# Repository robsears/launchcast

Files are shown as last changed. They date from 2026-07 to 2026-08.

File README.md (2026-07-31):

# LaunchCast

**Live telemetry from launchpad to landing.**

A LoRa telemetry payload for model rockets, with a handheld ground station. Built around the Adafruit Feather RP2040 RFM95.

## Hardware

### Rocket payload (~44 g)

| Role | Part | Price (USD) |
|---|---|---|
| Flight computer + LoRa | [Feather RP2040 RFM95](https://www.adafruit.com/product/5714) |  $29.95 |
| GPS | [Mini GPS PA1010D](https://www.adafruit.com/product/4415) | $29.95 |
| 9-DoF IMU | [LSM6DSOX + LIS3MDL](https://www.adafruit.com/product/4517) | $19.95 |
| Barometer | [BMP580](https://www.adafruit.com/product/6411) | $7.95 |
| Power | [3.7v 500 mAh LiPo](https://www.adafruit.com/product/1578) | $7.95 |
| Recovery aid | [PS1240 piezo](https://www.adafruit.com/product/160) | $1.50 |
| Antenna | [915 MHz spring](https://www.adafruit.com/product/4269) | $0.95 |
| Total | - | **$97.75** |

### Handheld ground station

| Role | Part | Price (USD) |
|---|---|---|
| Display | [Sharp Memory 2.7" 400×240](https://www.adafruit.com/product/4694) | $44.95 |
| Flight computer + LoRa | [Feather RP2040 RFM95](https://www.adafruit.com/product/5714) |  $29.95 |
| GPS | [Mini GPS PA1010D](https://www.adafruit.com/product/4415) | $29.95 |
| Power | [3.7v 2500 mAh LiPo](https://www.adafruit.com/product/5714) | $14.95 |
| Tactile Inputs | [Universal Proto-board PCBs 2cm x 8cm - 3 Pack](https://www.adafruit.com/product/4783)<br />[Colorful Round Tactile Button Switch Assortment - 15 pack](https://www.adafruit.com/product/1009) | $8.20|
| Antenna | [SMA to uFL/u.FL/IPX/IPEX RF Adapter Cable](https://www.adafruit.com/product/851)<br />[Mini GSM/Cellular Quad-Band Antenna - 2dBi SMA Plug](https://www.adafruit.com/product/1859) | $9.90 |
| Total | - | **$137.90** |

All sensors chain on a single I²C bus via STEMMA QT. Only the Feathers require soldering.

---

## Software

I run on NixOS and make heavy use of Nix flakes. This, plus direnv, ensures that any Nix user who clones this repo will have an identical workspace with all necessary tools. This is especially nice because you won't need to deal with Python or Conda, or polluting other environments. Everything you need is symlinked in .

Go set up Nix, and then you can get a local dev environment by running:

```
nix develop
```

Nix is also great because we can run tests and `make` scripts through it as well, ensuring the build environment also has everything it needs to do the work:

```
nix run .#test  
python -m pytest tests/ -q
....................................................................................................                                                                                                                                                                    [100%]
100 passed in 0.05s
```

Check out the `apps` section of `nix flake show` to see other `nix run .#` actions:

```
├───apps
│   ├───aarch64-darwin omitted (use '--all-systems' to show)
│   ├───aarch64-linux omitted (use '--all-systems' to show)
│   └───x86_64-linux
│       ├───check: app
│       ├───default: app
│       ├───deploy-ground: app
│       ├───deploy-rocket: app
│       ├───doctor: app
│       ├───libs-ground: app
│       ├───libs-rocket: app
│       ├───lint: app
│       ├───monitor: app
│       ├───pull-log: app
│       ├───test: app
│       └───volumes: app
```

**Language:** CircuitPython.

## Repository layout

```
launchcast/
├── common/
│   └── packet.py       # wire format -- single source of truth
├── rocket/
│   ├── code.py         # flight firmware
│   └── boot.py         # filesystem remount + volume label
├── ground/
│   ├── code.py         # handheld firmware
│   └── boot.py         # volume label
├── tests/
│   ├── test_packet.py
│   └── test_flight_state.py
├── conftest.py         # CircuitPython hardware stubs
├── docs/wiring/        # Fritzing sketches
├── nix/                # devshell, apps, shared package set
└── Makefile            # test, lint, deploy, pull flight logs
```

`common/packet.py` is copied to both boards at deploy time rather than
imported as a package. CircuitPython has a flat filesystem — `code.py` and
`packet.py` sit side by side on the device — so the firmware does a bare
`import packet`. `conftest.py` puts `common/` on `sys.path` so the same
import resolves in CI. Change the format string once; both sides stay in
sync because there is only one file.

The two boards are identical hardware running different firmware. `boot.py`
labels each volume (`LC-ROCKET` / `LC-GROUND`) so `make deploy-rocket`
cannot target the handheld when both are plugged in.

---

## Tests

```
nix run .#test          # or: make test
nix run .#check         # test + lint
```

100 tests, ~0.15 s. Two files, testing very different things.

**`test_packet.py`** covers the wire format. Sizes are contractual — 40 bytes
downlink, 7 up — and a change that breaks a round trip breaks both boards
silently. It also checks the things that only matter when something has gone
wrong: frames from stuck-high or stuck-low lines, wrong packet types, values
that saturate rather than wrapping. A clipped accelerometer reading must not
change sign, because that would look like the rocket reversed direction.

**`test_flight_state.py`** covers the state machine, which is the logic that
runs exactly once per flight, irreversibly, a few hundred meters up. It
synthesizes a pressure and acceleration profile for a plausible D12-5 flight,
feeds it through `FlightState` at the real sample rate, and asserts both the
state sequence and the transition timings. Boost must fire shortly after
ignition but not before `BOOST_MIN_MS`; apogee must land near the true peak;
states must never regress.

The pair worth understanding is `test_a_brief_bump_does_not_trigger_boost`
and `test_a_sustained_bump_does_trigger_boost`. They bracket `BOOST_MIN_MS`
from both sides — too lax and handling the rocket on the pad starts the
flight, too aggressive and a real launch is missed.

The firmware imports `board`, `busio`, `digitalio` and friends at module
scope, none of which exist off-device. `conftest.py` stubs them. Nothing
there simulates hardware behavior — anything needing a real peripheral is a
bench test, not a CI test.

`d12_profile` is a shape, not a simulation: 1.6 s burn, ballistic coast,
5 m/s descent. It exists so the state machine sees realistic transitions.
After the first flight it should be replaced with real log data, at which
point these become regression tests against measured behavior.

## License

Apache License 2.0. See `LICENSE`.

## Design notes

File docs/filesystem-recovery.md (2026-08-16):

# Recovering a Corrupted Board Filesystem

What happened during a firmware update session on the rocket board, how we
diagnosed it, and the runbook for fixing it if it happens again (on either
board).

## What happened

While iterating on `rocket/boot.py`'s flight-mode/dev-mode logic, the rocket
board went through a lot of hard resets and power cycles in a short window --
BOOTSEL/RESET combos, unplug/replug to force a fresh `supervisor.runtime.
usb_connected` check, etc. At some point one of those resets landed mid-write,
and the board's internal FAT filesystem came out of it corrupted.

Symptom: the CIRCUITPY drive mounted with garbled, unreadable filenames (mojibake
instead of `code.py` / `packet.py`), and the volume showed up labeled as a raw
serial number (`C0E0-F50B`) instead of `LC-ROCKET`. That serial-number fallback
is the tell -- it's what a file manager shows when the volume label stored in
the filesystem's own root directory structure is unreadable. Practically, this
meant the board wasn't running any recognizable `code.py`, so it stopped
transmitting telemetry entirely (the ground station showed `NO TELEMETRY
rejects: 0` -- nothing arriving over the radio at all, as opposed to `rejects`
climbing, which would mean packets arriving but failing to decode).

## Why reflashing CircuitPython alone didn't fix it

The first fix attempt was to reflash CircuitPython from its `.uf2` (see
[Recovery runbook](#recovery-runbook) below). That did *not* fix it -- same
garbled files, same `C0E0-F50B`, right after the reflash.

Reason: flashing a CircuitPython `.uf2` replaces the interpreter/firmware only.
It does **not** reformat the internal filesystem partition unless CircuitPython
can't mount it at all. This board's corruption was bad enough to garble
filenames but not bad enough to make CircuitPython refuse to mount it, so the
same damaged filesystem just came right back after the reflash.

The actual fix has to be an explicit filesystem reformat, from the CircuitPython
REPL:

```python
import storage
storage.erase_filesystem()
```

This is CircuitPython's built-in "the filesystem is corrupt, rebuild it" tool.
It erases and reformats the internal flash filesystem and reboots.

## A red herring along the way: no `/dev/ttyACM*`

Partway through recovery, the serial port disappeared entirely (no
`/dev/ttyACM*` device at all). That's expected, not a new failure: the RP2040's
UF2 bootloader (`RPI-RP2`, seen in `lsusb` as `2e8a:0003 Raspberry Pi RP2
Boot`) is mass-storage-only and never presents a serial/CDC interface. If
you're mid-recovery and lose the serial port, check `lsusb` for that ID first
-- it just means the board is sitting in the bootloader waiting for a `.uf2`,
not that something new broke. A stale Nautilus/file-manager window can also
keep showing an old (corrupted) mount after the board has already re-entered
the bootloader -- don't trust a file manager's cached view here; re-check with
`lsusb` and `find /run/media/$USER -maxdepth 1`.

## Recovery runbook

1. **Note the CircuitPython version first**, if `boot_out.txt` is still
   readable (it survives corruption that garbles the other files, since it's
   regenerated fresh on every boot). It'll look like:
   ```
   Adafruit CircuitPython 10.2.1 on 2026-05-13; Adafruit Feather RP2040 RFM with rp2040
   Board ID:adafruit_feather_rp2040_rfm
   ```
   Matching the version avoids introducing a CircuitPython upgrade as an extra
   variable while you're debugging something else.

2. **Enter the UF2 bootloader**: hold **BOOT**, press and release **RESET**
   while still holding BOOT (or hold BOOT while plugging in USB). A drive
   named `RPI-RP2` should appear. Confirm with `lsusb` if unsure --
   `2e8a:0003 Raspberry Pi RP2 Boot` means you're in.

3. **Copy the matching `.uf2`** (this repo keeps a copy of the one used for
   both boards at
   `docs/downloads/adafruit-circuitpython-adafruit_feather_rp2040_rfm-en_US-10.2.1.uf2`)
   onto `RPI-RP2`, and force a `sync` before the board has a chance to reset
   itself mid-write:
   ```
   cp docs/downloads/adafruit-circuitpython-*.uf2 /run/media/$USER/RPI-RP2/ && sync
   ```
   The board reboots on its own once the copy is complete.

4. **Reformat the filesystem from the REPL** -- this is the step that
   actually fixes corruption, not step 3:
   ```
   make monitor          # or screen/minicom on /dev/ttyACM0
   ```
   At the `>>>` prompt (Ctrl-C first if something's running):
   ```python
   import storage
   storage.erase_filesystem()
   ```
   The board erases, reformats, and reboots automatically.

5. **Confirm it's clean**: `make volumes` should now show a plain `CIRCUITPY`
   volume (not yet relabeled).

6. **Re-provision from the repo**:
   ```
   make setup-rocket      # or setup-ground -- labels the volume, needs a reset after
   #  ... reset the board ...
   make volumes           # confirm it now shows LC-ROCKET / LC-GROUND
   make libs-rocket        # or libs-ground -- reinstalls CircuitPython libraries,
                            # wiped along with everything else by the reformat
   make deploy-rocket      # or deploy-ground
   ```

## Prevention

The root trigger was resetting/unplugging the board while a write could still
be in flight -- easy to do when iterating quickly on `boot.py` and wanting a
truly fresh boot each time. Where practical, let a write finish and the OS
finish flushing (`sync`, or just give the "copied" progress bar/notification a
moment to clear) before pulling power or hitting RESET, especially right after
`boot.py`'s own remount dance runs.

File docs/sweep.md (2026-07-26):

# Buzzer Frequency Sweep 

The payload Feather has a little piezo buzzer soldered across D5/D6, which it uses to "chirp". Piezoelectric buzzers like this use [piezoelectric materials](https://en.wikipedia.org/wiki/Piezoelectricity), which essentially convert electricity to sound. More specifically, they use electric _frequencies_; simply applying a voltage across the material doesn't cause it to make a sound. It's the oscillation that does it.

Because of this, piezoelectric buzzers have a couple of [resonance frequencies](https://en.wikipedia.org/wiki/Resonance), at which they produce higher auditory volumes. The piezo buzzer I am using is a [PS1240](https://www.adafruit.com/product/160) ([specs](PS1240-piezo.pdf)), which indicates that peak volumes with an input frequency around 4500 Hz. But that's just from a random sample, and also it's based on a 3V input.

The reason for putting the buzzer across D5/D6 is I can oscillate the voltage of the pins from -3.3 to +3.3, giving me an actual range of anbout 6.6V across the leads, and we have no data on how loud we can get the buzzer with a 6V square-wave voltage.

To ensure we get the loudest frequency, we'll perform a sweep test with a cell phone SPL meter app. We'll do some coarse measurements to get an idea where the peaks are, and then another pass to refine it.

This is the code:

```python
"""
Finds the loudest drive frequency for THIS specific PS1240 in its mounting.
Piezo resonance is sharp and part-specific; the datasheet nominal (4 kHz) is
a starting point, not the answer.

Wiring: buzzer across D5 and D6 (differential drive, ~6.6 Vp-p).

Method:
  1. Run this with an SPL meter app on your phone at a FIXED distance
     (10 cm to match the datasheet, or 30 cm for convenience -- just keep
     it constant).
  2. Quiet room. Note the dB reading for each frequency as it's announced
     on the serial console.
  3. Find the peak, then narrow with FINE_SWEEP around it.

Differential drive note: two PWM channels, same frequency. CircuitPython
does not guarantee they run 180 deg out of phase, so you may see less than
the theoretical +6 dB over single-ended. Still the right way to wire it.
"""

import time
import board
import pwmio

# --- sweep configuration -----------------------------------------------------

COARSE_START = 2000
COARSE_STOP = 10000
COARSE_STEP = 250

HOLD_S = 3.0     # time to hold each tone (read the meter during this)
GAP_S = 1.0      # silence between tones
DUTY = 32768     # 50% square

# After the coarse sweep finds a peak, set this and re-run to narrow.
FINE = False
FINE_CENTER = 4000
FINE_SPAN = 400
FINE_STEP = 25

# --- drive -------------------------------------------------------------------

hi = pwmio.PWMOut(board.D5, frequency=COARSE_START, duty_cycle=0,
                  variable_frequency=True)
lo = pwmio.PWMOut(board.D6, frequency=COARSE_START, duty_cycle=0,
                  variable_frequency=True)

def tone(freq):
    hi.frequency = freq
    lo.frequency = freq
    hi.duty_cycle = DUTY
    lo.duty_cycle = DUTY

def silence():
    hi.duty_cycle = 0
    lo.duty_cycle = 0

def sweep(start, stop, step):
    print("--- sweep {}-{} Hz, step {} ---".format(start, stop, step))
    print("hold each tone for {:.0f}s, note the dB reading".format(HOLD_S))
    print()
    for freq in range(start, stop + 1, step):
        print(">>> {} Hz".format(freq))
        tone(freq)
        time.sleep(HOLD_S)
        silence()
        time.sleep(GAP_S)
    print()
    print("--- sweep complete ---")

# --- run ---------------------------------------------------------------------

silence()
time.sleep(1.0)

if FINE:
    sweep(FINE_CENTER - FINE_SPAN, FINE_CENTER + FINE_SPAN, FINE_STEP)
else:
    sweep(COARSE_START, COARSE_STOP, COARSE_STEP)

silence()
print("done. Peak frequency goes in BUZZER_HZ.")

while True:
    time.sleep(1)
```

For me, this ended up being about 5250 Hz, which I measured to be around 103 dB a few inches away.

In terms of sound attenuation, the volume of the buzzer at increasing distance  would roughly be:

| Distance (ft) | Decibels | Sounds like |
|---|---|---|
| 0 | 103 | Motorcycle |
| 10 | 63 | Normal speech |
| 25 | 55 | Light traffic |
| 50 | 49 | Light traffic |
| 100 | 43 | Soft music |
| 250 | 35 | Whisper |

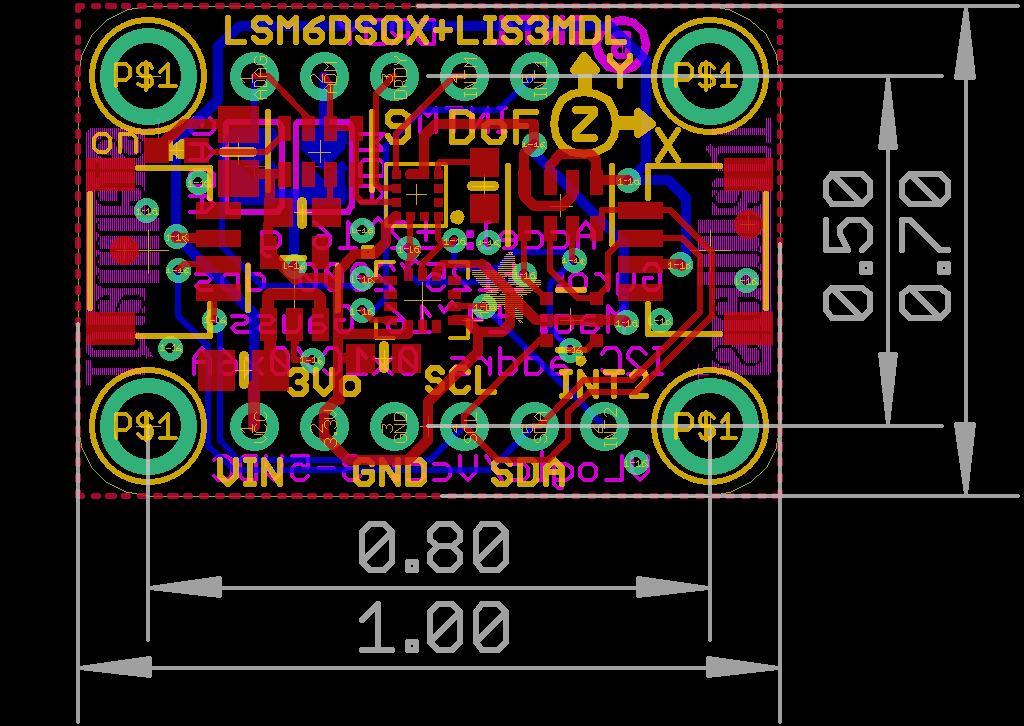
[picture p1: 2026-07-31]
docs/images/lsm6dsox-lis3mdl.png

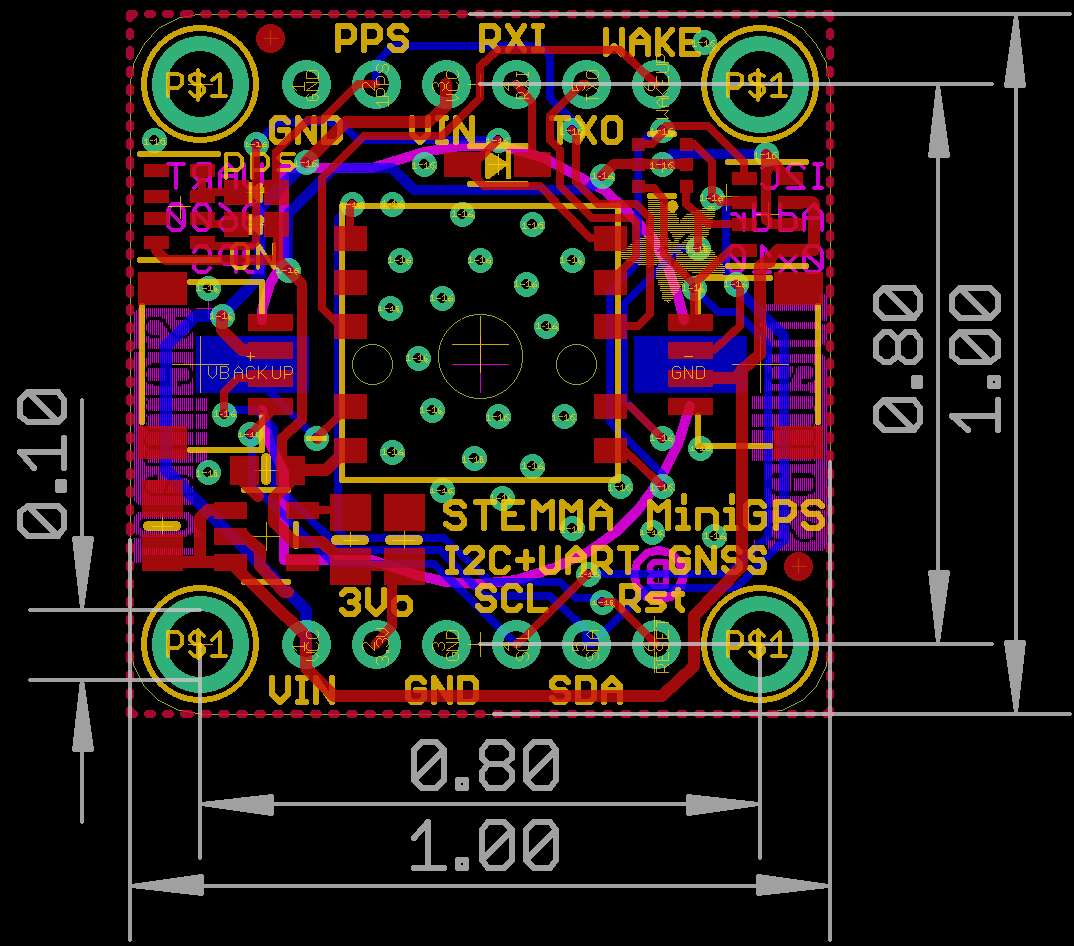
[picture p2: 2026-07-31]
docs/images/gps.png

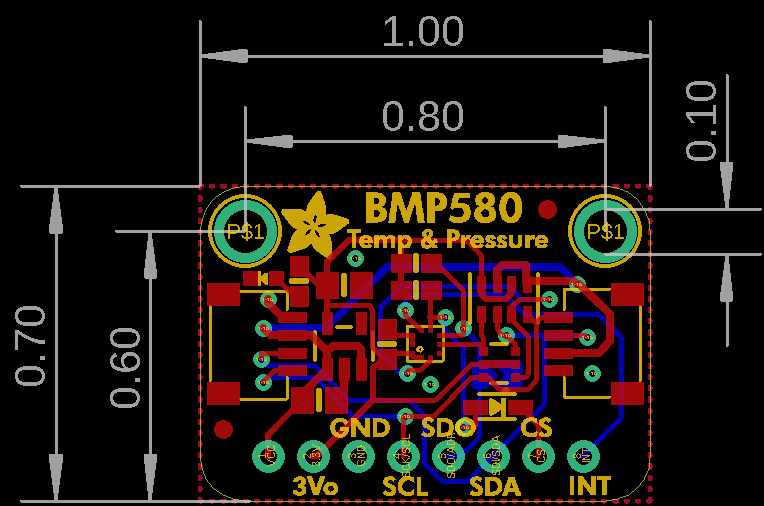
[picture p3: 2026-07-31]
docs/images/bmp580.png

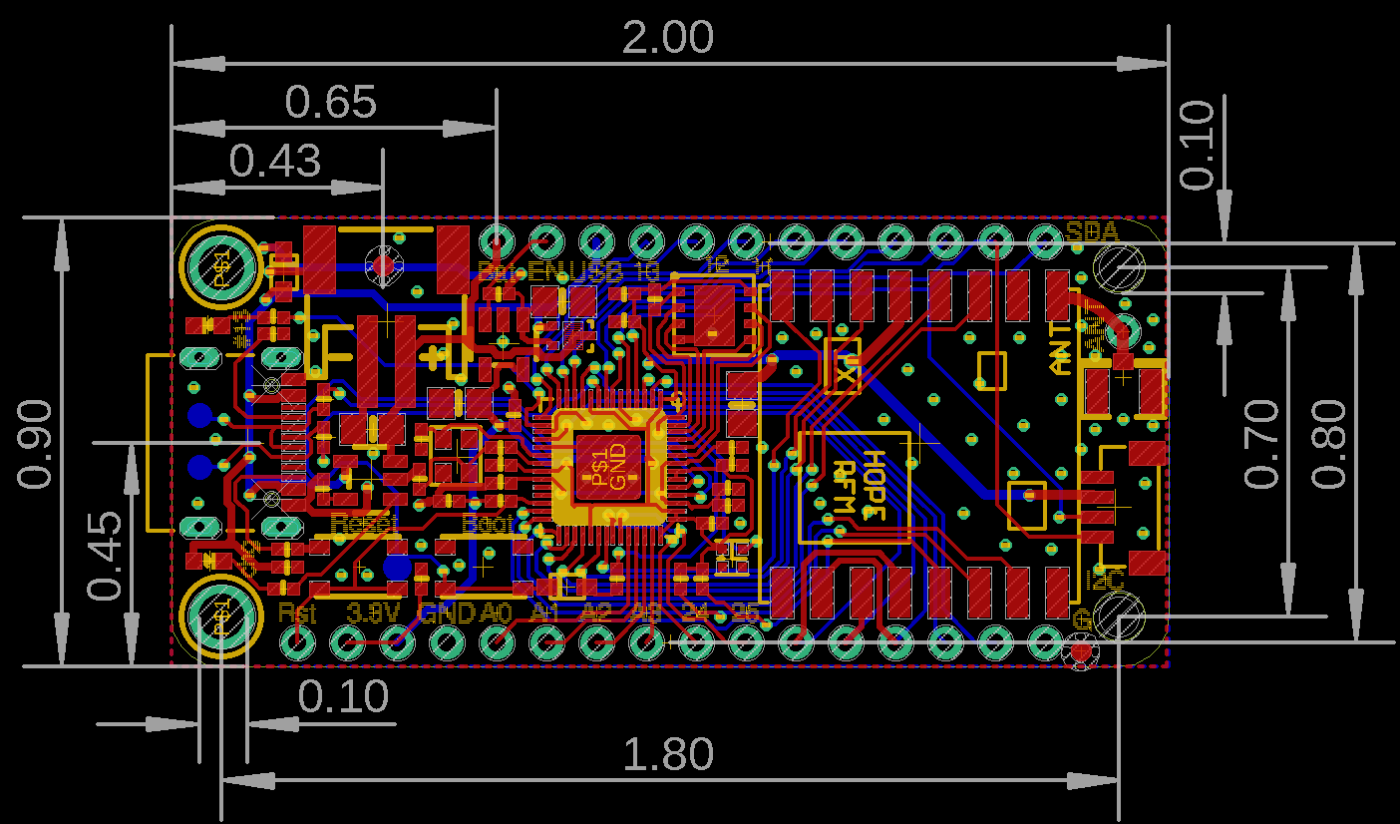
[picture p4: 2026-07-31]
docs/images/feather.png

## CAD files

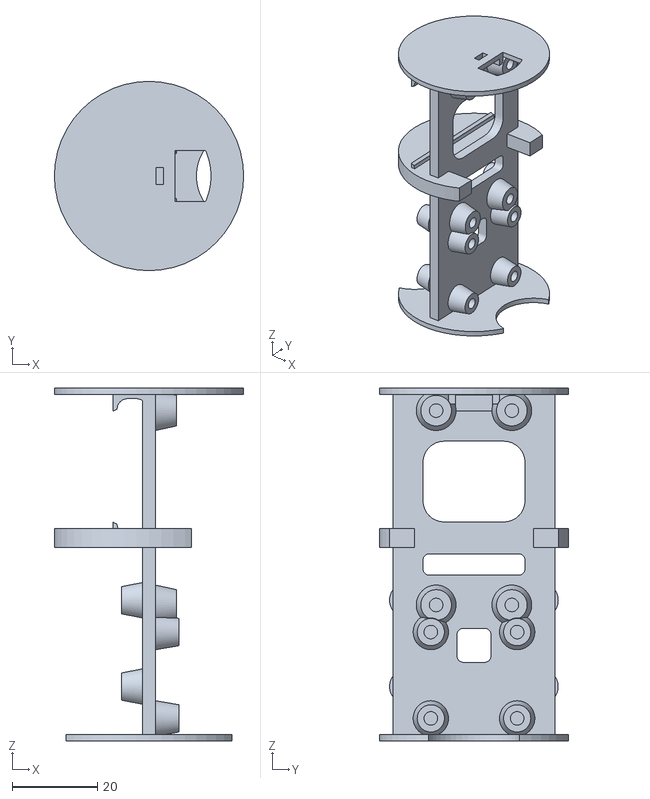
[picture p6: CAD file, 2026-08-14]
docs/cad/sled.stl
44.5 x 44.5 x 83.0

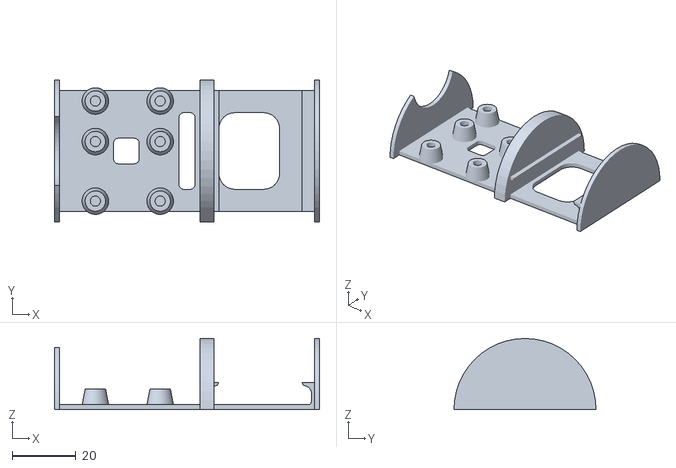
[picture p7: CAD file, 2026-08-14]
docs/cad/sled-side-b.stl
83.0 x 44.5 x 22.2

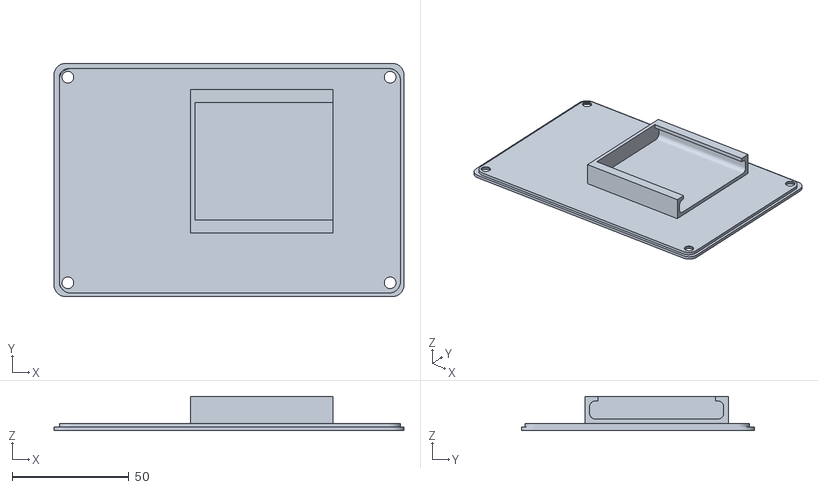
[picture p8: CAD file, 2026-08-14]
docs/cad/handheld - lid no txt.stl
150.0 x 100.0 x 14.8

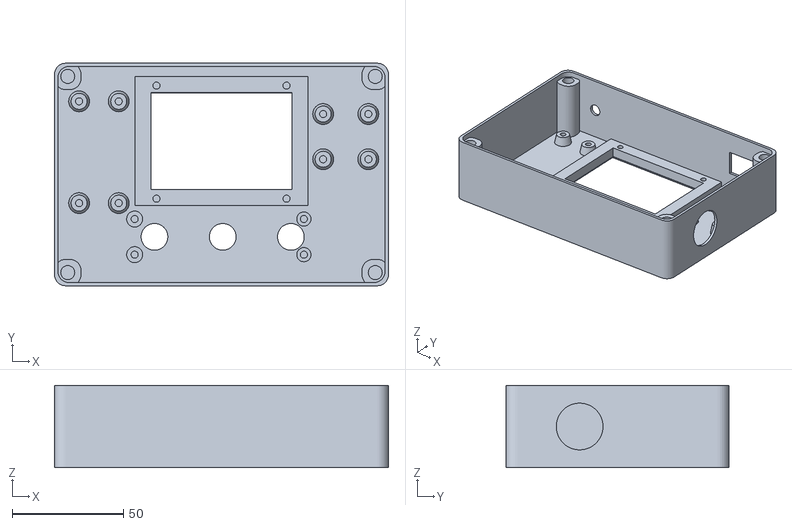
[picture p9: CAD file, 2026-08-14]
docs/cad/handheld - box.stl
150.0 x 100.0 x 37.0

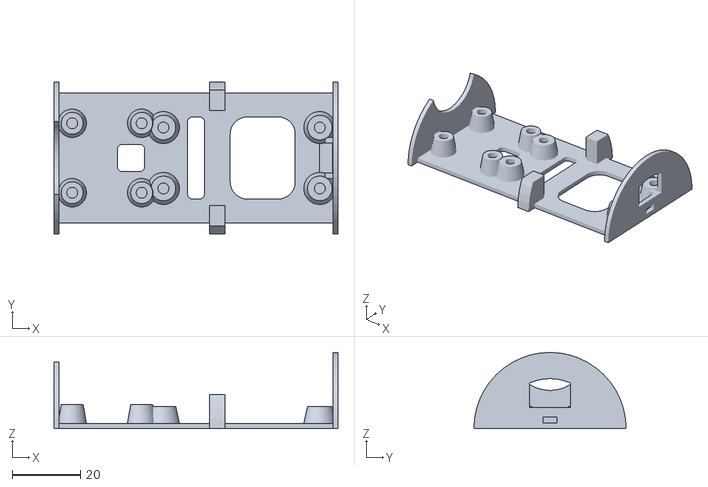
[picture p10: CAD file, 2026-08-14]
docs/cad/sled-side-a.stl
83.0 x 44.5 x 22.2

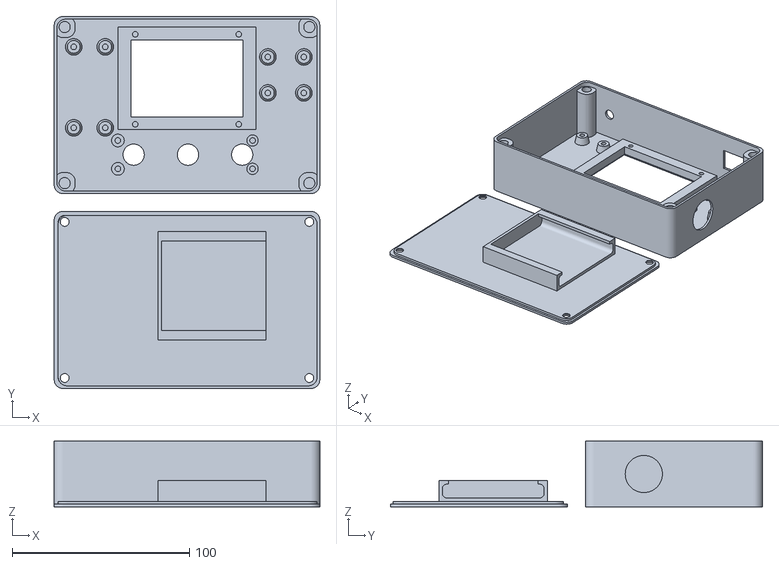
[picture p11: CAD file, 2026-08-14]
docs/cad/handheld.stl
150.0 x 210.0 x 37.0

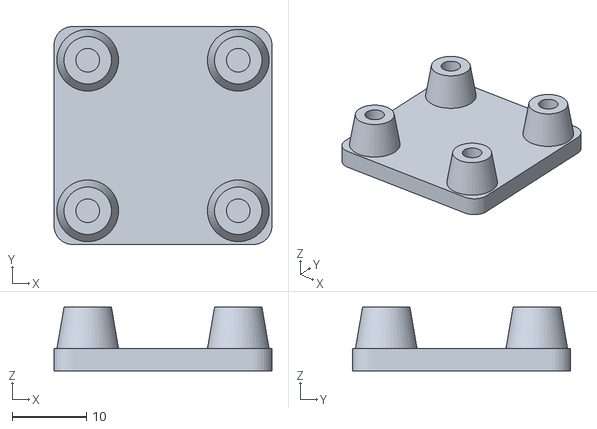
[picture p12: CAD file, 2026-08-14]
docs/cad/gps_coupon.stl
29.4 x 29.4 x 8.60

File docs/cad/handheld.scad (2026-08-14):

SHOW_GHOSTS = false;
SHOW_LID    = true;
SHOW_BOX    = false;
$fn = 48;

// ---- Footprints ----
PCB_RADIUS    = 2.5;    // Corner radius of the PCB
PCB_THICKNESS = 2.0;    // Thickness of PCB
PCB_HOLE_D    = 2.5;    // Diameter of pass-thru holes on PCB

// ---- Feather ----
FEATHER_Z      = 50.8;  // 2.00"
FEATHER_Y      = 22.9;  // 0.90"
FEATHER_HOLE_Z = 45.7;  // 1.80"
FEATHER_HOLE_Y = 17.8;  // 0.70"

// ---- GPS ----
GPS_Z      = 25.4;      // 1.00"
GPS_Y      = 25.4;      // 1.00"
GPS_HOLE_Z = 20.3;      // 0.80"
GPS_HOLE_Y = 20.3;      // 0.80"

// ---- Cutouts --
USB_CHARGER_D = 21.0;
ANTENNA_D     = 6.5;
ONOFF_X       = 19.5;
ONOFF_Z       = 13.5;

// ---- Battery ----
BATTERY_X = 61.0;
BATTERY_Y = 57.5;
BATTERY_Z = 7.75;
BATTERY_HOLDER_THICKNESS = 2.0;

// ---- Button Pad ----
BUTTON_PAD_X = 80.0;
BUTTON_PAD_Y = 20.0;
BUTTON_PAD_Z = PCB_THICKNESS;
BUTTON_PAD_POST_H = 18.1; //OAL of the button
BUTTON_PAD_HOLE_X = 76;
BUTTON_PAD_HOLE_Y = 16;
BUTTON_PAD_HOLE_D = 2.0;
BUTTON_BASE_X     = 12.0;
BUTTON_BASE_Y     = 12.0;
BUTTON_BASE_Z     = 6.4;
BUTTON_PLUNGER_X  = 3.8;
BUTTON_PLUNGER_Y  = 3.8;
BUTTON_PLUNGER_Z  = 3.9;
BUTTON_BUTTON_BASE_H = 1.4;
BUTTON_BUTTON_BASE_D = 12.8;
BUTTON_BUTTON_BODY_H = 4.4;
BUTTON_BUTTON_BODY_D = 12.0;

// ---- Inserts (M2.5 x D3.0 x L4.0) ----
INSERT_BORE_D          = 3.2; // DIA of pilot hole
INSERT_DEPTH           = 5.0;
INSERT_WALL_THICKNESS  = 2.0;
INSERT_WALL_THICKNESS_MIN = 1.6;
INSERT_FLOOR_THICKNESS = 1.0;

POST_OD_HEAVY = ((INSERT_BORE_D / 2) + INSERT_WALL_THICKNESS)*2;  // Feather, battery bar
POST_OD_LIGHT = ((INSERT_BORE_D / 2) + INSERT_WALL_THICKNESS)*2;  // GPS, IMU, BMP
POST_H_STD    = max(4.5, INSERT_DEPTH);
POST_H_GPS    = max(5.6, INSERT_DEPTH);;  // clears 4.12mm coin holder + 1.5mm

// -- Screen dimensions
SCREEN_PCB_X = 63.5;              // 2.50"
SCREEN_PCB_Y = 55.88;             // 2.20"
SCREEN_PCB_HOLES_X = 58.42;       // 2.30"
SCREEN_PCB_HOLES_Y = 50.8;        // 2.00"
SCREEN_PCB_HOLE_OFFSET = 2.54;     //
SCREEN_DISPLAY_X = SCREEN_PCB_X;  // TODO: measure?
SCREEN_DISPLAY_Y = 43.4;          // Caliper measurement
SCREEN_DISPLAY_Y_OFFSET = 6.75;   // Caliper measurement
SCREEN_DISPLAY_Z = PCB_THICKNESS; // TODO: measure? Does it matter?
SCREEN_DISPLAY_GRADE = 5;

// Unit dimensions
HANDHELD_THICKNESS = 1.5;
HANDHELD_TOP_X     = 150;
HANDHELD_TOP_Y     = 100;
HANDHELD_TOP_Z     = SCREEN_DISPLAY_Z;
HANDHELD_OVERALL_Z = 37;
HANDHELD_FILLET    = 5.0;
HANDHELD_INSERT_THICKNESS = INSERT_DEPTH + INSERT_FLOOR_THICKNESS;
HANDHELD_DISPLAY_BORDER = (INSERT_BORE_D + 2 * INSERT_WALL_THICKNESS) * 2;
HANDHELD_DISPLAY_X = (HANDHELD_TOP_X - SCREEN_DISPLAY_X)/2;
HANDHELD_DISPLAY_Y = (HANDHELD_TOP_Y - SCREEN_DISPLAY_Y - 20);

HEAT_SET_INSERT_D     = 6.3;
HEAT_SET_INSERT_WALL  = 2.8;
HEAT_SET_INSERT_DEPTH = 8.0;

echo(16.5 + BATTERY_Z + 2*BATTERY_HOLDER_THICKNESS + 2.5 * HANDHELD_THICKNESS);

module rounded_rect(x, y, z, r, $fn=32) {
  translate([x/2, y/2, 0]) {
    linear_extrude(height=z)
    minkowski() {
      square([x - 2*r, y - 2*r], center=true);
      circle(r=r);
    }    
  }
}

module ghost(y, z, col) {
  color(col,0.35)
    rounded_rect(y, z, PCB_THICKNESS, PCB_RADIUS);
}

module screen_ghost() {
  pcb_hole_x = (SCREEN_PCB_X - SCREEN_PCB_HOLES_X)/2;
  pcb_hole_y = (SCREEN_PCB_Y - SCREEN_PCB_HOLES_Y)/2;
  union() {
    difference() {
      color("YellowGreen",1) {
        cube([SCREEN_PCB_X, SCREEN_PCB_Y, PCB_THICKNESS]);
      }
      translate ([pcb_hole_x, pcb_hole_y, 0]) { cylinder(h = PCB_THICKNESS, r = PCB_HOLE_D/2); }
      translate ([pcb_hole_x + SCREEN_PCB_HOLES_X, pcb_hole_y, 0]) { cylinder(h = PCB_THICKNESS, r = PCB_HOLE_D/2); }
      translate ([pcb_hole_x, pcb_hole_y + SCREEN_PCB_HOLES_Y, 0]) { cylinder(h = PCB_THICKNESS, r = PCB_HOLE_D/2); }
      translate ([pcb_hole_x + SCREEN_PCB_HOLES_X, pcb_hole_y + SCREEN_PCB_HOLES_Y, 0]) { cylinder(h = PCB_THICKNESS, r = PCB_HOLE_D/2); }
    }
    color("Black",0.35)
      translate([0, SCREEN_DISPLAY_Y_OFFSET, PCB_THICKNESS]) {
        cube([SCREEN_DISPLAY_X, SCREEN_DISPLAY_Y, PCB_THICKNESS]);
      }
  }
}

// adapted from docs:
// https://en.wikibooks.org/wiki/OpenSCAD_User_Manual/Primitive_Solids#polyhedron
module screen_cutout() {
  CubePoints = [
    [  0,                                      0,                                        0 ],                          //0
    [ SCREEN_DISPLAY_X,                        0,                                        0 ],                          //1
    [ SCREEN_DISPLAY_X,                        SCREEN_DISPLAY_Y,                         0 ],                          //2
    [ 0,                                       SCREEN_DISPLAY_Y,                         0 ],                          //3
    [ -SCREEN_DISPLAY_GRADE,                   -SCREEN_DISPLAY_GRADE,                    HANDHELD_INSERT_THICKNESS ],  //4
    [ SCREEN_DISPLAY_X + SCREEN_DISPLAY_GRADE, -SCREEN_DISPLAY_GRADE,                    HANDHELD_INSERT_THICKNESS ],  //5
    [ SCREEN_DISPLAY_X + SCREEN_DISPLAY_GRADE, SCREEN_DISPLAY_Y + SCREEN_DISPLAY_GRADE,  HANDHELD_INSERT_THICKNESS ],  //6
    [ -SCREEN_DISPLAY_GRADE,                   SCREEN_DISPLAY_Y + SCREEN_DISPLAY_GRADE,  HANDHELD_INSERT_THICKNESS  ]  //7
  ];
    
  CubeFaces = [
    [0,1,2,3],  // bottom
    [4,5,1,0],  // front
    [7,6,5,4],  // top
    [5,6,2,1],  // right
    [6,7,3,2],  // back
    [7,4,0,3]]; // left
    
  polyhedron( CubePoints, CubeFaces );
}

module post(x, y, h, od) {
  rotate([0, -90, 0]) {
    translate([x, y, 0]) {
      difference() {
        cylinder(h = h, r1 = od/2, r2 = 1.3 * (od/2));
        translate([0, 0, INSERT_DEPTH-h]) {
          cylinder(h = INSERT_DEPTH, r = INSERT_BORE_D/2);
        }
      }
      if (SHOW_GHOSTS) {
        translate([0, 0, h - INSERT_DEPTH]) {
          color("Magenta",0.35)
            cylinder(h = INSERT_DEPTH, r = INSERT_BORE_D/2);
        }
      }
    }
  }
}

module post_feather(x, y) {
  post(x, y, POST_H_STD, POST_OD_HEAVY);
}

module post_gps(x, y) {
  post(x, y, POST_H_GPS, POST_OD_LIGHT);
}

// --- Feather Mounts + Ghost
// Posts flush with X=0, YZ at midpoint
module feather_posts() {
  rotate([90, -90, 0]) {
    translate([POST_H_STD, 0, 0]) {
      if (SHOW_GHOSTS) {
        translate([0, -FEATHER_Y/2, -FEATHER_Z/2]) {rotate([90, 0, 90]) {feather_ghost();}}
      }
      translate([0, -FEATHER_HOLE_Y/2, FEATHER_HOLE_Z/2]) {
        post_feather(0, 0);
        post_feather(0, FEATHER_HOLE_Y);
        post_feather(-FEATHER_HOLE_Z, 0);
        post_feather(-FEATHER_HOLE_Z, FEATHER_HOLE_Y);
      }
    }
  }
}

module feather_ghost() {
  difference() {
    ghost(FEATHER_Y, FEATHER_Z, "GreenYellow");
    translate([0, -FEATHER_HOLE_Y/2, -FEATHER_HOLE_Z/2]) {
      rotate([0, 90, 0]) {
        translate([0, 0, 0]) {cylinder(h = PCB_THICKNESS, r = PCB_HOLE_D/2);}
        translate([0, FEATHER_HOLE_Y, 0]) {cylinder(h = PCB_THICKNESS, r = PCB_HOLE_D/2);}
        translate([-FEATHER_HOLE_Z, 0, 0]) {cylinder(h = PCB_THICKNESS, r = PCB_HOLE_D/2);}
        translate([-FEATHER_HOLE_Z, FEATHER_HOLE_Y, 0]) {cylinder(h = PCB_THICKNESS, r = PCB_HOLE_D/2);}
      }
    }
  }
}

// --- GPS Mounts + Ghost
// Posts flush with X=0, YZ at midpoint
module gps_posts() {
  rotate([90, -90, 0]) {
    translate([POST_H_GPS, 0, 0]) {
      if (SHOW_GHOSTS) {
        translate([0, -GPS_Y/2, -GPS_Z/2]) {rotate([90, 0, 90]) {gps_ghost();}}
      }
      translate([0, -GPS_HOLE_Y/2, GPS_HOLE_Z/2]) {
        post_gps(0, 0);
        post_gps(0, GPS_HOLE_Y);
        post_gps(-GPS_HOLE_Z, 0);
        post_gps(-GPS_HOLE_Z, GPS_HOLE_Y);
      }
    }
  }
}

module gps_ghost() {
  difference() {
    ghost(GPS_Y, GPS_Z, "DeepSkyBlue");
    translate([0, -GPS_HOLE_Y/2, -GPS_HOLE_Z/2]) {
      rotate([0, 90, 0]) {
        translate([0, 0, 0]) {cylinder(h = PCB_THICKNESS, r = PCB_HOLE_D/2);}
        translate([0, GPS_HOLE_Y, 0]) {cylinder(h = PCB_THICKNESS, r = PCB_HOLE_D/2);}
        translate([-GPS_HOLE_Z, 0, 0]) {cylinder(h = PCB_THICKNESS, r = PCB_HOLE_D/2);}
        translate([-GPS_HOLE_Z, GPS_HOLE_Y, 0]) {cylinder(h = PCB_THICKNESS, r = PCB_HOLE_D/2);}
      }
    }
  }
}

module button() {
  union() {
    cube([BUTTON_BASE_X, BUTTON_BASE_Y, BUTTON_BASE_Z]);
    translate([(BUTTON_BASE_X - BUTTON_PLUNGER_X)/2, (BUTTON_BASE_Y - BUTTON_PLUNGER_Y)/2, BUTTON_BASE_Z]) {
      cube([BUTTON_PLUNGER_X, BUTTON_PLUNGER_Y, BUTTON_PLUNGER_Z]);
    }
    translate([
      BUTTON_BASE_X/2, BUTTON_BASE_Y/2, BUTTON_BASE_Z + BUTTON_PLUNGER_Z
    ]) { cylinder(h = BUTTON_BUTTON_BASE_H, r = BUTTON_BUTTON_BASE_D/2); }
    translate([
      BUTTON_BASE_X/2, BUTTON_BASE_Y/2, BUTTON_BASE_Z + BUTTON_PLUNGER_Z + BUTTON_BUTTON_BASE_H
    ]) { cylinder(h = BUTTON_BUTTON_BODY_H, r = BUTTON_BUTTON_BODY_D/2); }
  }
}
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

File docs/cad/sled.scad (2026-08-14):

SHOW_GHOSTS = false;
SHOW_COUPONS = false;
SHOW_SLED = true;
$fn = 48;

// ---- Spine ----
SPINE_Z       = 80.0;
SPINE_Y       = 38.0;   // set by battery pocket (30 + 2*4mm walls); bore limit
SPINE_THICK   = 3.0;

// ---- Inserts (M2.5 x D3.0 x L4.0) ----
INSERT_BORE_D = 3.2; // DIA of pilot hole
INSERT_DEPTH  = 5.0;
INSERT_WALL_MIN_THICKNESS = 1.6;
INSERT_WALL_MAX_THICKNESS = 2.0;
BOLT_HOLE_D = 3.2;      // clearance for M3 alignment bolts (or 2.6 for M2.5)

// ---- Posts (sized to load) ----
POST_OD_HEAVY = ((INSERT_BORE_D / 2) + INSERT_WALL_MAX_THICKNESS)*2;  // Feather, battery bar
POST_OD_LIGHT = ((INSERT_BORE_D / 2) + INSERT_WALL_MIN_THICKNESS)*2;  // GPS, IMU, BMP
POST_H_STD    = max(4.5, INSERT_DEPTH);
POST_H_GPS    = max(5.6, INSERT_DEPTH);;  // clears 4.12mm coin holder + 1.5mm

// ---- Footprints ----
PCB_RADIUS    = 2.5;    // Corner radius of the PCB
PCB_THICKNESS = 2.0;    // Thickness of PCB
PCB_HOLE_D    = 2.5;    // Diameter of pass-thru holes on PCB

// ---- Feather ----
FEATHER_Z      = 50.8;  // 2.00"
FEATHER_Y      = 22.9;  // 0.90"
FEATHER_HOLE_Z = 45.7;  // 1.80"
FEATHER_HOLE_Y = 17.8;  // 0.70"

// ---- GPS ----
GPS_Z      = 25.4;      // 1.00"
GPS_Y      = 25.4;      // 1.00"
GPS_HOLE_Z = 20.3;      // 0.80"
GPS_HOLE_Y = 20.3;      // 0.80"

// ---- IMU (LSM6DSOX+LIS3MDL) ----
IMU_Z = 25.4;           // 1.00"
IMU_Y = 17.8;           // 0.70"
IMU_HOLE_Z = 20.3;      // 0.80"
IMU_HOLE_Y = 12.7;      // 0.50"

// ---- BMP580 ----
// NOTE: This footprint only has 2 mounting holes
BMP_Z          = 25.4;  // 1.00"
BMP_Y          = 17.8;  // 0.70"
BMP_HOLE_Z     = 20.3;  // 0.80"
BMP_HOLE_INSET = 2.5;   // 0.10" (from edge... see "Calculated")

// ---- Battery LP503035 ----
BATT_Z           = 35.0;// Z-lengh of battery
BATT_Y           = 30.0;// Y-width of battery
BATT_THICK       = 5.0; // Thickness of battery
BATT_POCKET_WALL = 4.0; // do NOT increase (bore limit)

// ---- On/Off switch ----
// https://www.amazon.com/dp/B0GSVGVN2N
ONOFF_Z = 3.8;
ONOFF_Y = 8.7;
ONOFF_X = 3.9;
ONOFF_SWITCH_HOLE_Z = 3.0;
ONOFF_SWITCH_HOLE_Y = 1.75;
ONOFF_SWITCH_HOLE_X = 4.0;
ONOFF_TOP_THICK = 0.6;
ONOFF_SIDE_THICK = 1.6;

// --- Payload Coins
COIN_D              = 44.5;  // 
COIN_THICK          = 1.5;
COIN_SPINE_THICK    = 4.5;
COIN_BATT_CUTOUT_D  = 29.2;
COIN_CUTOUT_D       = 22.2;

// ---- Calculated ----
BMP_HOLE_Y  = BMP_Y - 2 * BMP_HOLE_INSET;      // Calculated position of BMP sensor hole
SENSOR_GAP  = (SPINE_Y - IMU_Y - BMP_Y)/3;     // Gap between the sensors on Side B
FEATHER_GAP = (SPINE_Z - FEATHER_Z - GPS_Z)/3; // Gab between the Feather, GPS and edges on Side A

module rounded_rect(w, h, thick, r, $fn=32) {
  rotate([90, 0, 90]) {
    linear_extrude(height=thick)
    minkowski() {
      square([w - 2*r, h - 2*r], center=true);
      circle(r=r);
    }
  }
}

module rounded_cube(size, radius) {
    width = size[0];
    depth = size[1];
    height = size[2];
    
    hull() {
        // Place cylinders at each corner
        translate([radius, radius, 0])
            cylinder(r=radius, h=height, $fn=32);
        translate([width-radius, radius, 0])
            cylinder(r=radius, h=height, $fn=32);
        translate([radius, depth-radius, 0])
            cylinder(r=radius, h=height, $fn=32);
        translate([width-radius, depth-radius, 0])
            cylinder(r=radius, h=height, $fn=32);
    }
}

module ghost(y, z, col) {
  color(col,0.35)
    rounded_rect(y, z, PCB_THICKNESS, PCB_RADIUS);
}

//ONOFF_Z = 100;
//ONOFF_Y = 8.7;
//ONOFF_X = 3.9;
//ONOFF_SWITCH_HOLE_Z = 3.0;
//ONOFF_SWITCH_HOLE_Y = 1.75;
//ONOFF_SWITCH_HOLE_X = 4.0;
//ONOFF_TOP_THICK = 0.6;
//ONOFF_SIDE_THICK = 1.6;

module spine() {
  difference() {
    union() {
      translate([-1, -(ONOFF_Y + 2 * ONOFF_SIDE_THICK)/2, SPINE_Z+COIN_THICK-ONOFF_SWITCH_HOLE_Z-ONOFF_TOP_THICK-.2]) {
        difference() {
          translate([0, 0, 0]) {cube([
            ONOFF_X + 2 * ONOFF_SIDE_THICK,
            (ONOFF_Y + 2 * ONOFF_SIDE_THICK),
            ONOFF_Z
          ]);}
        }
      }
      translate([-SPINE_THICK/2, -SPINE_Y/2, 0]) {
        // Spine
        cube([SPINE_THICK, SPINE_Y, SPINE_Z]);
        translate([-BATT_POCKET_WALL-3, 0, SPINE_Z]) {
          rotate([-90, 0, 0]) {
            difference() {
              // Battery holder material
              cube([BATT_POCKET_WALL+5, SPINE_Y-2, BATT_Z + 3]);
              translate([1, (SPINE_Y - BATT_Y - 2)/2-2, -5]) {
                // Battery pocket
                union() {
                  rounded_cube([BATT_THICK + 2, BATT_Y + 2, BATT_Z + 20], PCB_RADIUS);
                  translate([-2, 2.5, 0]) {
                    rounded_cube([BATT_THICK, BATT_Z - 8, BATT_Z + 20], PCB_RADIUS);
                  }
                }
              }
            }
          }
        }
      }
    }
    // Mass cutout #1
    cutout_gap = 7;
    translate([-COIN_D/2, 0, SPINE_Z - COIN_THICK - (SPINE_Y - (2*cutout_gap))/2 - cutout_gap]) {
      rounded_rect(
        (SPINE_Y - (2*cutout_gap)),
        (SPINE_Y - (2*cutout_gap) - 5),
        COIN_D,
        5
      );
    }

    // Mass cutout #2
    translate([-COIN_D/2, 0, SPINE_Z/2 - 19]) {
      rounded_rect(
        8,
        8,
        COIN_D,
        1.5
      );
    }
    
    // Mass cutout #3
    translate([-COIN_D/2, 0, SPINE_Z/2]) {
      rounded_rect(
        (SPINE_Y - (2*cutout_gap)),
        5,
        COIN_D,
        1.5
      );
    }
    
    // ONOFF Cutout
    translate([-1, -(ONOFF_Y + 2 * ONOFF_SIDE_THICK)/2, SPINE_Z+COIN_THICK-ONOFF_SWITCH_HOLE_Z-ONOFF_TOP_THICK-1.2]) {
      translate([ONOFF_SIDE_THICK ,ONOFF_SIDE_THICK, -ONOFF_TOP_THICK]) {
        union() {
          cube([ONOFF_X + 5, ONOFF_Y, ONOFF_Z]);
          translate([(ONOFF_X - ONOFF_SWITCH_HOLE_Y)/2, (ONOFF_Y - ONOFF_SWITCH_HOLE_X)/2, ONOFF_Z]) {
            cube([ONOFF_SWITCH_HOLE_Y, ONOFF_SWITCH_HOLE_X, ONOFF_SWITCH_HOLE_Z]);
          }
        }
      }
    }
  }
  // Spine coin
  translate([0, 0, SPINE_Z/2 + 4]) {
    difference() {
      cylinder(r = COIN_D/2, h = COIN_SPINE_THICK);
      translate([0, -(FEATHER_Y+5)/2, -FEATHER_Z/2]) {
        cube([FEATHER_Y, FEATHER_Y+5, FEATHER_Z]);
      }
      translate([10, -COIN_D/2, -FEATHER_Z/2]) {
        cube([COIN_D, COIN_D, FEATHER_Z]);
      }
    }
  }
}

module post(x, y, h, od) {
  rotate([0, -90, 0]) {
    translate([x, y, 0]) {
      difference() {
        cylinder(h = h, r1 = od/2, r2 = 1.3 * (od/2));
        translate([0, 0, INSERT_DEPTH-h]) {
          cylinder(h = INSERT_DEPTH, r = INSERT_BORE_D/2);
        }
      }
      if (SHOW_GHOSTS) {
        translate([0, 0, h - INSERT_DEPTH]) {
          color("Magenta",0.35)
            cylinder(h = INSERT_DEPTH, r = INSERT_BORE_D/2);
        }
      }
    }
  }
}

module post_feather(x, y) {
  post(x, y, POST_H_STD, POST_OD_HEAVY);
}

module post_gps(x, y) {
  post(x, y, POST_H_GPS, POST_OD_LIGHT);
}

module post_std(x, y) {
  post(x, y, POST_H_STD, POST_OD_LIGHT);
}

// --- Feather Mounts + Ghost
// Posts flush with X=0, YZ at midpoint
module feather_posts() {
  translate([POST_H_STD, 0, 0]) {
    if (SHOW_GHOSTS) {
      feather_ghost();
    }
    translate([0, -FEATHER_HOLE_Y/2, FEATHER_HOLE_Z/2]) {
      post_feather(0, 0);
      post_feather(0, FEATHER_HOLE_Y);
      post_feather(-FEATHER_HOLE_Z, 0);
      post_feather(-FEATHER_HOLE_Z, FEATHER_HOLE_Y);
    }
  }
}

module feather_ghost() {
  difference() {
    ghost(FEATHER_Y, FEATHER_Z, "GreenYellow");
    translate([0, -FEATHER_HOLE_Y/2, -FEATHER_HOLE_Z/2]) {
      rotate([0, 90, 0]) {
        translate([0, 0, 0]) {cylinder(h = PCB_THICKNESS, r = PCB_HOLE_D/2);}
        translate([0, FEATHER_HOLE_Y, 0]) {cylinder(h = PCB_THICKNESS, r = PCB_HOLE_D/2);}
        translate([-FEATHER_HOLE_Z, 0, 0]) {cylinder(h = PCB_THICKNESS, r = PCB_HOLE_D/2);}
        translate([-FEATHER_HOLE_Z, FEATHER_HOLE_Y, 0]) {cylinder(h = PCB_THICKNESS, r = PCB_HOLE_D/2);}
      }
    }
  }
}

// --- GPS Mounts + Ghost
// Posts flush with X=0, YZ at midpoint
module gps_posts() {
  translate([POST_H_GPS, 0, 0]) {
    if (SHOW_GHOSTS) {
      gps_ghost();
    }
    translate([0, -GPS_HOLE_Y/2, GPS_HOLE_Z/2]) {
      post_gps(0, 0);
      post_gps(0, GPS_HOLE_Y);
      post_gps(-GPS_HOLE_Z, 0);
      post_gps(-GPS_HOLE_Z, GPS_HOLE_Y);
    }
  }
}

module gps_ghost() {
  difference() {
    ghost(GPS_Y, GPS_Z, "DeepSkyBlue");
    translate([0, -GPS_HOLE_Y/2, -GPS_HOLE_Z/2]) {
      rotate([0, 90, 0]) {
        translate([0, 0, 0]) {cylinder(h = PCB_THICKNESS, r = PCB_HOLE_D/2);}
        translate([0, GPS_HOLE_Y, 0]) {cylinder(h = PCB_THICKNESS, r = PCB_HOLE_D/2);}
        translate([-GPS_HOLE_Z, 0, 0]) {cylinder(h = PCB_THICKNESS, r = PCB_HOLE_D/2);}
        translate([-GPS_HOLE_Z, GPS_HOLE_Y, 0]) {cylinder(h = PCB_THICKNESS, r = PCB_HOLE_D/2);}
      }
    }
  }
}
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

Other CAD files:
docs/cad/handheld - lid.stl

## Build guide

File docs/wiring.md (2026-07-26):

# Wiring Guide

The Feather is based on the "32-bit dual-core ARM Cortex-M0+ microcontroller designed by Raspberry Pi Ltd. In January 2021, it was released as part of the Raspberry Pi Pico board." [[1](https://en.wikipedia.org/wiki/RP2040)]. The pinout is this:

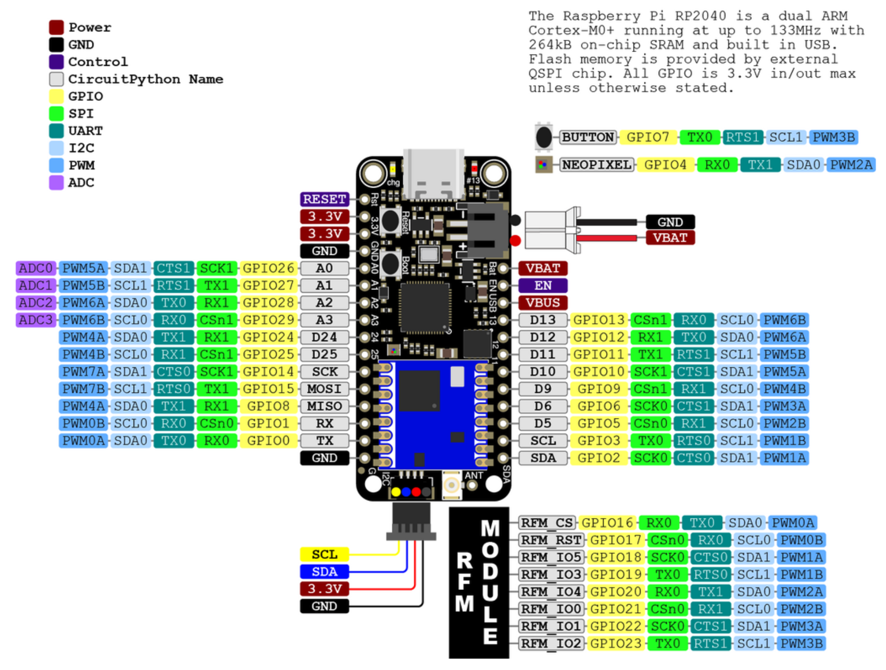
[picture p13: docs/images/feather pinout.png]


Use this as a reference for wiring the payload and handheld units.

## Payload

Wiring the payload is pretty simple. The modules for the GPS, motion and environment daisy-chain via 4-pin JST SH. The only thing I put on here was a small piezo buzzer across D5/D6, and a spring antenna on the ANT pad.

I also made up a quick and dirty voltage divider with two 100 kΩ resistors:

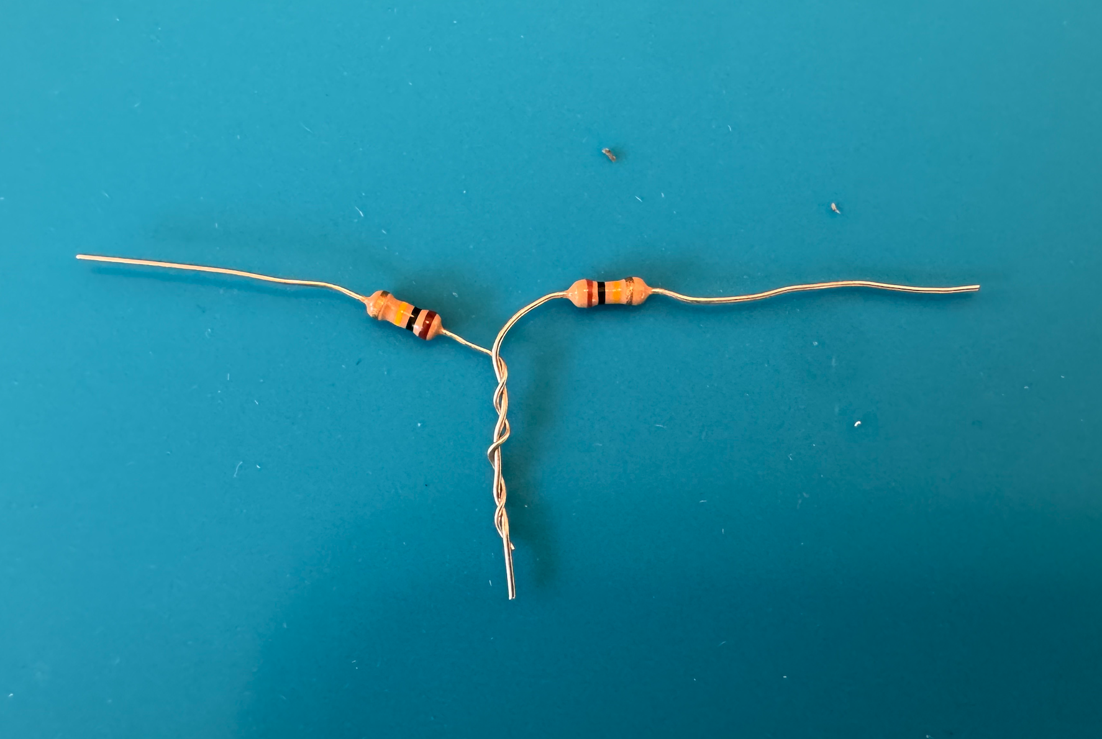
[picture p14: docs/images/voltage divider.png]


I measured the resistor to be 99.9 kΩ, right is 97.2 kΩ, it’s 198.4 kΩ across both. The joined leads were soldered to A0, and the other ends are soldered to BAT and GND, respectively.

The daisy-chain is Feather -> BMP580 -> LSM6DSOX/LIS3MDL -> PA1010D GPS. It's easy enough to put together. In the REPL, you can confirm the I²C addresses of the components:

```
import board
i2c = board.STEMMA_I2C()
i2c.try_lock()
print([hex(a) for a in i2c.scan()])
['0x10', '0x1c', '0x47', '0x6a']
i2c.unlock()
```

## Handheld

Wiring the handheld is a bit more complicated due to the screen. I soldered headers to this one because space isn't really a concern. 

PA1010D GPS is connected to the Feather via Qwiic JST SH 4-pin, same as the payload. I also soldered a small spring antenna to the ANT pad.

Also like the payload, I made a voltage divider (measured at 99.9 kΩ and 99.6 kΩ, and 198.6 kΩ across both), and cut some female-female jumper wires in half and soldered them to the ends. I also used some heat shrink tubes. That way I could plug it into the headers:

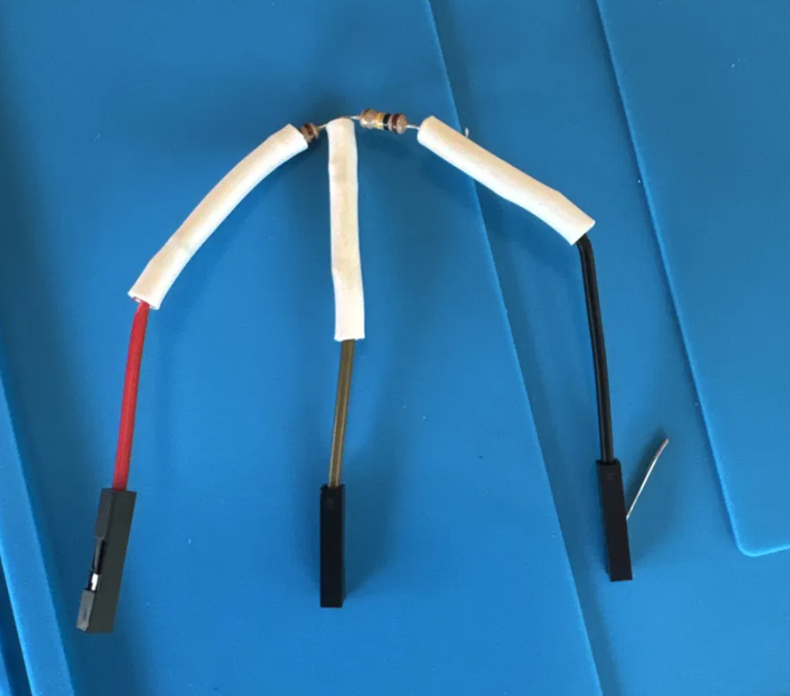
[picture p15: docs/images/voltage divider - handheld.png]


Just like the payload, the ends connect to BAT and GND, and the joined end connects to A0.

Wiring the screen takes 5 wires:

| Adafruit SHARP Memory Display Breakout | Wire Color | Adafruit Feather RP2040 Pin |
|---|---|---|
| 3x3 | Red | 3.3V |
| GND | Black | GND |
| CLK | Green | SCK |
| DI | Orange | MOSI |
| CS | Yellow | D6 |

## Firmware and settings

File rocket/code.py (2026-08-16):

"""
LaunchCast flight firmware -- rocket payload.

Runs on an Adafruit Feather RP2040 RFM95 (PID 5714) with:
  BMP580 barometer, LSM6DSOX+LIS3MDL IMU, PA1010D GPS  (I2C via STEMMA QT)
  PS1240 piezo across D5/D6 (differential drive)
  onboard NeoPixel as status indicator
  500 mAh LiPo through a slide switch to BAT

Design contract:
  - The downlink is a MONITOR. The flash log is the DATASET. Radio packets
    drop; flash does not. Never let a radio failure stall the log loop.
  - Loop order is: sense -> log -> state -> radio. Sensing is never skipped;
    radio work is best-effort and time-boxed. Logging itself only runs from
    ARMED onward -- BOOT/IDLE can sit on a bench or pad for hours across dev
    sessions and would otherwise fill the flash with nothing useful.
  - Apogee is detected from BAROMETRIC VELOCITY, not acceleration.
    Acceleration is ~1 g through the entire coast/descent transition.

Copy packet.py to the board alongside this file.
"""

import time
import math
import struct
import board
import busio
import digitalio
import pwmio
import analogio
import microcontroller
import supervisor

import packet
from packet import State, Command, Sensor

# --- Tuning ------------------------------------------------------------------

LOG_PATH = "/flight.bin"    # Binary log format; CSV takes more overhead
IMU_HZ = 100                # Acclerometer/gyro: target sample rate
BARO_HZ = 25                # Pressure/temp: target sample rate
GPS_HZ = 1                  # PA1010D (GPS) default NMEA rate
TX_HZ_IDLE = 0.5            # Broadcast rate when not in flight
TX_HZ_FLIGHT = 2.0          # Broadcast rate when in flight
BOOST_THRESHOLD_G = 3.0     # Any acceleration > 3.0g means "liftoff!"
BOOST_MIN_MS = 150          # Acceleration must persist this long to avoid accidental bumps
COAST_THRESHOLD_G = 1.5     # Below 1.5g, we're done boosting and now coasting
APOGEE_VEL_MPS = 1.0        # *Vertical* velocity below this at apex
DESCENT_VEL_MPS = -2.0      # Sustained negative velocity -> under chute
LANDED_VEL_MPS = 0.5        # Landing detection: motion near-zero velocity...
LANDED_ALT_M = 15.0         # ...near ground level
LANDED_HOLD_MS = 3000       # ...for this long, means we've landed.

BUZZER_HZ = 5250            # Piezo max-vol freq.
CHIRP_MS = 1000             # Duration of a commanded chirp

BATT_DIVIDER = 2.0          # Onboard voltage divider ratio; 1.0 if reading BAT directly
BATT_SAMPLES = 8            # Number of samples to average for estimating battery life

VEL_ALPHA = 0.3             # Vertical velocity is unreliable via GPS at high speed, short
                            # flights, so instead we derive it from barometric pressure.
                            # The BMP580 gives us this, but the readings a *noisy*, and
                            # measuring in 10^-1 Hz-scale increments amplifies this noise.
                            # So we use first-order IIR low-pass filtering, an exponentially
                            # weighted moving average: y = α·x + (1−α)·y_prev. Our `VEL_ALPHA`
                            # is the α value. α = 1 means no filtering. α → 0 means the value
                            # never changes. α = 0.3 behaves roughly like averaging the
                            # last 3–4 readings.

# --- Hardware ----------------------------------------------------------------


class Hardware:
    """Owns every peripheral. Any sensor may be None if it failed to init."""

    def __init__(self):
        self.i2c = None
        self.baro = None
        self.imu = None
        self.mag = None
        self.gps = None
        self.radio = None
        self.pixel = None
        self.buzz_hi = None
        self.buzz_lo = None
        self.vbat = None
        self.errors = []

    def init_all(self):
        self._init_pixel()
        self._init_buzzer()
        self._init_battery()
        self._init_i2c()
        self._init_baro()
        self._init_imu()
        self._init_gps()
        self._init_radio()
        return len(self.errors) == 0

    # -- individual peripherals, each failing independently -------------------

    def _init_pixel(self):
        try:
            import neopixel

            self.pixel = neopixel.NeoPixel(board.NEOPIXEL, 1, brightness=0.2)
            self.pixel[0] = (0, 0, 32)
        except Exception as e:
            self.errors.append("pixel: {}".format(e))

    def _init_buzzer(self):
        try:
            self.buzz_hi = pwmio.PWMOut(
                board.D5, frequency=BUZZER_HZ, duty_cycle=0, variable_frequency=True
            )
            self.buzz_lo = pwmio.PWMOut(
                board.D6, frequency=BUZZER_HZ, duty_cycle=0, variable_frequency=True
            )
        except Exception as e:
            self.errors.append("buzzer: {}".format(e))

    def _init_battery(self):
        try:
            pin = getattr(board, "VOLTAGE_MONITOR", None) or board.A0
            self.vbat = analogio.AnalogIn(pin)
        except Exception as e:
            self.errors.append("vbat: {}".format(e))

    def _init_i2c(self):
        try:
            self.i2c = board.STEMMA_I2C()
        except Exception:
            try:
                self.i2c = busio.I2C(board.SCL, board.SDA)
            except Exception as e:
                self.errors.append("i2c: {}".format(e))

    def _init_baro(self):
        if not self.i2c:
            return
        try:
            import adafruit_bmp5xx

            self.baro = adafruit_bmp5xx.BMP5XX_I2C(self.i2c)
        except Exception as e:
            self.errors.append("baro: {}".format(e))

    def _init_imu(self):
        if not self.i2c:
            return
        try:
            from adafruit_lsm6ds.lsm6dsox import LSM6DSOX

            self.imu = LSM6DSOX(self.i2c)
        except Exception as e:
            self.errors.append("imu: {}".format(e))
        try:
            import adafruit_lis3mdl

            self.mag = adafruit_lis3mdl.LIS3MDL(self.i2c)
        except Exception as e:
            self.errors.append("mag: {}".format(e))

    def _init_gps(self):
        if not self.i2c:
            return
        try:
            import adafruit_gps

            self.gps = adafruit_gps.GPS_GtopI2C(self.i2c, debug=False)
            self.gps.send_command(b"PMTK314,0,1,0,1,0,0,0,0,0,0,0,0,0,0,0,0,0,0,0")
            self.gps.send_command(b"PMTK220,1000")
            # SBAS/WAAS narrows single-unit error from ~5-10m to ~1-3m under open
            # sky (No effect indoors/under tree cover). Two independent receivers
            # still won't agree to zero -- their errors are uncorrelated.
            self.gps.send_command(b"PMTK313,1")
            self.gps.send_command(b"PMTK301,2")
        except Exception as e:
            self.errors.append("gps: {}".format(e))

    def _init_radio(self):
        try:
            import adafruit_rfm9x

            spi = board.SPI()
            cs = digitalio.DigitalInOut(board.RFM_CS)
            rst = digitalio.DigitalInOut(board.RFM_RST)
            self.radio = adafruit_rfm9x.RFM9x(spi, cs, rst, 915.0)
            self.radio.tx_power = 20
            self.radio.spreading_factor = 7
            self.radio.signal_bandwidth = 125000
            self.radio.coding_rate = 5
            self.radio.enable_crc = True
            try:
                self.radio.sync_word = packet.SYNC_WORD
            except Exception:
                pass  # some library versions expose this differently
        except Exception as e:
            self.errors.append("radio: {}".format(e))

    # -- helpers --------------------------------------------------------------

    def battery_volts(self):
        if not self.vbat:
            return 0.0
        total = 0
        for _ in range(BATT_SAMPLES):
            total += self.vbat.value
        avg = total / BATT_SAMPLES
        return (avg / 65535.0) * 3.3 * BATT_DIVIDER

    def buzz_on(self, freq=BUZZER_HZ):
        """Differential drive: two pins, opposite phase, ~6.6 Vp-p."""
        if not (self.buzz_hi and self.buzz_lo):
            return
        self.buzz_hi.frequency = freq
        self.buzz_lo.frequency = freq
        self.buzz_hi.duty_cycle = 32768
        self.buzz_lo.duty_cycle = 32768  # see note in loop(): phase is approximate

    def buzz_off(self):
        if self.buzz_hi:
            self.buzz_hi.duty_cycle = 0
        if self.buzz_lo:
            self.buzz_lo.duty_cycle = 0

    def set_pixel(self, rgb):
        if self.pixel:
            try:
                self.pixel[0] = rgb
            except Exception:
                pass

    def sensor_flags(self, log_ok=False):
        """Bitfield of peripherals that came up. Called once after init and
        again whenever something is known to have failed mid-flight."""
        from packet import Sensor
        flags = 0
        if self.baro:
            flags |= Sensor.BARO
        if self.imu:
            flags |= Sensor.IMU
        if self.mag:
            flags |= Sensor.MAG
        if self.gps:
            flags |= Sensor.GPS
        if self.vbat:
            flags |= Sensor.BATT
        if log_ok:
            flags |= Sensor.LOG
        return flags

# --- Flight state machine ----------------------------------------------------
# NOTE: NeoPixels on Feathers are often GRB order, not RGB. If colors come out wrong,
# that's why. Set `neopixel.NeoPixel(..., pixel_order=neopixel.GRB)`
PIXEL_FOR_STATE = {
    State.BOOT: (0, 0, 32),     # Dim blue
    State.IDLE: (16, 16, 0),    # Dim yellow
    State.ARMED: (0, 32, 0),    # Green
    State.BOOST: (48, 16, 0),   # Orange
    State.COAST: (0, 16, 32),   # Cyan
    State.APOGEE: (32, 0, 32),  # Magenta
    State.DESCENT: (0, 24, 24), # Teal
    State.LANDED: (48, 0, 0),   # Red (brightest)
}


class FlightState:
    """Owns state transitions and the barometric velocity estimate.

    Altitude is measured above ground level (AGL), referenced to a ground datum captured at ARM time.
    """

    def __init__(self):
        self.state = State.BOOT
        self.ground_pressure = None
        self.alt_m = 0.0
        self.vel_mps = 0.0
        self.max_alt_m = 0.0
        self._last_alt = None
        self._last_t = None
        self._boost_start = None
        self._landed_start = None
        self.entered_ms = 0

    def set_ground_reference(self, pressure_hpa):
        self.ground_pressure = pressure_hpa

    def _pressure_to_alt(self, pressure_hpa):
        """Standard barometric formula, referenced to the ground datum."""
        if not self.ground_pressure or pressure_hpa <= 0:
            return 0.0
        ratio = pressure_hpa / self.ground_pressure
        return 44330.0 * (1.0 - math.pow(ratio, 0.1903))

    def update_altitude(self, pressure_hpa, now_ms):
        self.alt_m = self._pressure_to_alt(pressure_hpa)
        if self.alt_m > self.max_alt_m:
            self.max_alt_m = self.alt_m

        if self._last_alt is not None and self._last_t is not None:
            dt = (now_ms - self._last_t) / 1000.0
            if dt > 0.001:
                raw = (self.alt_m - self._last_alt) / dt
                self.vel_mps += VEL_ALPHA * (raw - self.vel_mps)

        self._last_alt = self.alt_m
        self._last_t = now_ms

    def transition(self, new_state, now_ms):
        if new_state != self.state:
            self.state = new_state
            self.entered_ms = now_ms
            return True
        return False

    def update(self, accel_mag_g, now_ms):
        """Advance the state machine. Returns True if the state changed.

        BOOT and IDLE and ARMED transitions are driven externally (sensor
        init, uplink commands). Everything from BOOST onward is autonomous
        and one-way -- there is no path back to ARMED in flight.
        """
        s = self.state

        if s == State.ARMED:
            if accel_mag_g >= BOOST_THRESHOLD_G:
                if self._boost_start is None:
                    self._boost_start = now_ms
                elif now_ms - self._boost_start >= BOOST_MIN_MS:
                    return self.transition(State.BOOST, now_ms)
            else:
                self._boost_start = None

        elif s == State.BOOST:
            if accel_mag_g < COAST_THRESHOLD_G:
                return self.transition(State.COAST, now_ms)

        elif s == State.COAST:
            # Apogee is a VELOCITY event, not an acceleration event.
            if abs(self.vel_mps) <= APOGEE_VEL_MPS or self.vel_mps < 0:
                return self.transition(State.APOGEE, now_ms)

        elif s == State.APOGEE:
            if self.vel_mps <= DESCENT_VEL_MPS:
                return self.transition(State.DESCENT, now_ms)

        elif s == State.DESCENT:
            settled = abs(self.vel_mps) <= LANDED_VEL_MPS and self.alt_m <= LANDED_ALT_M
            if settled:
                if self._landed_start is None:
                    self._landed_start = now_ms
                elif now_ms - self._landed_start >= LANDED_HOLD_MS:
                    return self.transition(State.LANDED, now_ms)
            else:
                self._landed_start = None

        return False


# --- Flight log --------------------------------------------------------------

# t_ms, state, alt, vel, pressure, temp, ax, ay, az, gx, gy, gz
LOG_FMT = "<IBffffffffff"
LOG_SIZE = struct.calcsize(LOG_FMT)  # 45 bytes


class FlightLog:
    """Append-only binary log. Buffers in RAM, flushes on a size threshold.

    If the filesystem is read-only (USB connected without boot.py remount),
    every method degrades to a no-op and the flight continues.
    """

    def __init__(self, path=LOG_PATH, flush_bytes=1024):
        self.path = path
        self.flush_bytes = flush_bytes
        self.buf = bytearray()
        self.enabled = False
        self.records = 0
        self.dropped = 0
        try:
            with open(self.path, "ab") as f:
                f.write(b"")
            self.enabled = True
        except (OSError, RuntimeError):
            self.enabled = False

    def write(self, t_ms, state, alt, vel, pressure, temp, accel, gyro):
        if not self.enabled:
            self.dropped += 1
            return
        try:
            self.buf += struct.pack(
                LOG_FMT,
                t_ms & 0xFFFFFFFF,
                state,
                alt,
                vel,
                pressure,
                temp,
                accel[0],
                accel[1],
                accel[2],
                gyro[0],
                gyro[1],
                gyro[2],
            )
            self.records += 1
            if len(self.buf) >= self.flush_bytes:
                self.flush()
        except Exception:
            self.dropped += 1

    def flush(self):
        if not self.enabled or not self.buf:
            return
        try:
            with open(self.path, "ab") as f:
                f.write(self.buf)
            self.buf = bytearray()
        except Exception:
            self.enabled = False

    def clear(self):
        """Truncate the log and drop any unflushed records.

        Called when a bench ARM is disarmed without ever reaching BOOST --
        that arm cycle produced no flight data worth keeping, and bench
        ARM/DISARM cycles are frequent enough during dev to otherwise refill
        the flash the same way idle bench time used to.
        """
        if not self.enabled:
            return
        try:
            with open(self.path, "wb"):
                pass
            self.buf = bytearray()
            self.records = 0
            self.dropped = 0
        except Exception:
            self.enabled = False


# --- Main --------------------------------------------------------------------


def ms():
    return time.monotonic_ns() // 1_000_000


def accel_magnitude(a):
    return math.sqrt(a[0] * a[0] + a[1] * a[1] + a[2] * a[2]) / 9.80665


def main():
    hw = Hardware()
    hw.init_all()

    fs = FlightState()
    log = FlightLog()
    sensors = hw.sensor_flags(log_ok=log.enabled)
    present, missing = Sensor.decode(sensors)
    print("sensors up:", " ".join(present) or "NONE")
    if missing:
        print("sensors MISSING:", " ".join(missing))
    if not Sensor.flight_ready(sensors):
        print("*** NOT FLIGHT READY -- barometer, IMU, and log are required")

    # Everything below runs even if some sensors failed. A missing GPS
    # should not prevent a flight; a missing barometer degrades the state
    # machine to accel-only and is worth knowing about on the ground.
    for err in hw.errors:
        print("INIT FAIL:", err)

    if hw.baro is None:
        print("WARNING: no barometer -- altitude and apogee unavailable")

    # Sensor settling. The BMP580 needs a few reads before it is trustworthy.
    t0 = ms()
    while ms() - t0 < 2000:
        if hw.baro:
            try:
                _ = hw.baro.pressure
            except Exception:
                pass
        time.sleep(0.05)

    fs.transition(State.IDLE, ms())
    hw.set_pixel(PIXEL_FOR_STATE[State.IDLE])
    print("IDLE -- waiting for ARM from handheld")

    # Cadence tracking
    next_imu = 0
    next_baro = 0
    next_gps = 0
    next_tx = 0
    next_rx = 0

    counter = 0
    last_seq = None
    chirp_until = 0

    accel = (0.0, 0.0, 0.0)
    gyro = (0.0, 0.0, 0.0)
    pressure = 0.0
    temp_c = 0.0
    accel_g = 0.0
    lat = 0.0
    lon = 0.0
    has_fix = False
    sats = 0
    batt = 0.0
    batt_checked = 0

    imu_period = 1000 // IMU_HZ
    baro_period = 1000 // BARO_HZ
    gps_period = 1000 // GPS_HZ

    while True:
        now = ms()

        # -- sense: IMU (highest rate) ---------------------------------------
        if now >= next_imu:
            next_imu = now + imu_period
            if hw.imu:
                try:
                    accel = hw.imu.acceleration  # m/s^2
                    gyro = hw.imu.gyro  # rad/s
                    accel_g = accel_magnitude(accel)
                except Exception:
                    pass

        # -- sense: barometer -------------------------------------------------
        if now >= next_baro:
            next_baro = now + baro_period
            if hw.baro:
                try:
                    pressure = hw.baro.pressure
                    temp_c = hw.baro.temperature
                    fs.update_altitude(pressure, now)
                except Exception:
                    pass

        # -- log: every IMU sample from ARMED onward, regardless of anything
        # else. BOOT/IDLE are excluded -- unlike a real flight, they can last
        # indefinitely (bench testing, sitting on the pad waiting), and would
        # otherwise fill the flash with nothing useful before liftoff.
        if fs.state not in (State.BOOT, State.IDLE):
            log.write(now, fs.state, fs.alt_m, fs.vel_mps, pressure, temp_c, accel, gyro)

        # -- state machine ----------------------------------------------------
        if fs.update(accel_g, now):
            hw.set_pixel(PIXEL_FOR_STATE.get(fs.state, (16, 16, 16)))
            print("-> {}  alt={:.1f}m vel={:.1f}m/s".format(
                State.name(fs.state), fs.alt_m, fs.vel_mps))
            if fs.state == State.LANDED:
                log.flush()

        # -- sense: GPS (slow, and never allowed to block) --------------------
        if now >= next_gps:
            next_gps = now + gps_period
            if hw.gps:
                try:
                    hw.gps.update()
                    if hw.gps.has_fix:
                        has_fix = True
                        lat = hw.gps.latitude or 0.0
                        lon = hw.gps.longitude or 0.0
                        sats = hw.gps.satellites or 0
                    else:
                        has_fix = False
                except Exception:
                    pass

        # -- battery: slow, and only when not in powered flight ---------------
        if now - batt_checked > 5000 and fs.state not in (State.BOOST, State.COAST):
            batt_checked = now
            batt = hw.battery_volts()

        # -- radio: receive commands -----------------------------------------
        if hw.radio and now >= next_rx:
            next_rx = now + 100
            try:
                pkt = hw.radio.receive(timeout=0.0)
            except Exception:
                pkt = None
            if pkt:
                parsed = packet.unpack_command(bytes(pkt))
                if parsed:
                    seq, cmd = parsed
                    if seq != last_seq:  # reject replays
                        last_seq = seq
                        if cmd == Command.ARM and fs.state == State.IDLE:
                            if not Sensor.flight_ready(sensors):
                                print("ARM REFUSED -- not flight ready")
                                # 600ms steady tone = refusal
                                chirp_until = now + 600
                            else:
                                fs.set_ground_reference(pressure)
                                fs.transition(State.ARMED, now)
                                hw.set_pixel(PIXEL_FOR_STATE[State.ARMED])
                                print("ARMED  ground_p={:.2f}".format(pressure))
                        elif cmd == Command.DISARM and fs.state == State.ARMED:
                            fs.transition(State.IDLE, now)
                            hw.set_pixel(PIXEL_FOR_STATE[State.IDLE])
                            # ARMED -> IDLE only happens via an explicit DISARM
                            # while still ARMED -- BOOST is never detected, so
                            # this arm cycle logged nothing worth keeping.
                            # A real flight never takes this path back to IDLE.
                            log.clear()
                            print("DISARMED (log cleared)")
                        elif cmd == Command.CHIRP:
                            chirp_until = now + CHIRP_MS
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

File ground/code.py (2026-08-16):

"""
LaunchCast ground station firmware -- handheld receiver.

Runs on an Adafruit Feather RP2040 RFM95 (PID 5714) with:
  Sharp Memory Display 2.7" 400x240 (PID 4694) over SPI
  PA1010D GPS (I2C via STEMMA QT)
  Three momentary buttons on D9/D10/D11, active-low with internal pull-ups
  2500 mAh LiPo through a slide switch to BAT

Design contract:
  - The display refreshes on a TIMER, not on packet arrival. This satisfies
    the Sharp panel's VCOM polarity-inversion requirement and, more usefully,
    distinguishes "no new data" from "firmware crashed."
  - The last valid GPS fix from the rocket is LATCHED. When the final packets
    drop out behind terrain, you walk toward the last known position. This is
    the single most valuable feature in the file.
  - Staleness is displayed explicitly. A frozen number with no age is a lie.
  - Buttons are captured by keypad.Keys, a background scan independent of
    the main loop, so a slow GPS/display call can't cause a press to be
    dropped. Hold-duration math still runs on the main loop's own clock
    (not the event's timestamp -- different clock base, do not mix).

Copy packet.py to the board alongside this file.
"""

import time
import gc
import board
import busio
import digitalio
import analogio
import keypad
import supervisor

import packet
from packet import State, Command, Sensor
from display_util import text
from hold_tracker import HoldTracker
import screen_header
import screen_footer
import screen_flight
import screen_recovery
import screen_diagnostics

# --- Tuning ------------------------------------------------------------------
GPS_HZ = 1              # Local GPS refresh rate

LINK_STALE_MS = 3000    # No packet for this long -> show as stale
LINK_LOST_MS = 15000    # No packet for this long -> show as LOST

HOLD_MS = 2000          # ARM/DISARM requires a deliberate hold
DEBOUNCE_MS = 50        # keypad.Keys scan interval. Debounce happens in the
                        # background at this cadence regardless of what the
                        # main loop is doing, so a slow GPS/display call can't
                        # cause a press to be missed.
GRACE_MS = 250          # HoldTracker bridges a release-then-re-press of the
                        # same key within this window, so a brief mechanical
                        # bounce mid-hold doesn't restart HOLD_MS or misfire
                        # as a tap. Adds the same delay to genuine tap
                        # dispatch (it now finalizes GRACE_MS after release
                        # instead of immediately) -- should be imperceptible
                        # for a physical button, but lower it if CHIRP starts
                        # feeling laggy.

CMD_CONFIRM_FRAMES = 3  # payload telemetry frames to see before declaring an
                        # ARM/DISARM failed. Counting frames rather than
                        # elapsed time follows the payload's own TX rate
                        # (TX_HZ_IDLE/TX_HZ_FLIGHT), so the window is neither
                        # too short at low rate nor needlessly long at high
                        # rate. A link-lost fallback below still applies when
                        # no frames are arriving at all to count.

BATT_DIVIDER = 2.0      # Onboard voltage divider ratio; 1.0 if reading BAT directly
BATT_SAMPLES = 8        # Number of samples to average for estimating battery life

# Below this, treat "USB connected" as USB-power-only, not charging -- the
# BAT rail reads low/unstable with no cell attached (e.g. slide switch left
# open), and we don't want that showing up as a false CHARGING indicator.
# Verify empirically on real hardware (switch open + USB in) and adjust.
BATT_PRESENT_MIN_V = 2.5

# --- Display --------------------------------------------------------

DISPLAY_HZ = 2.0    # Display refresh rate; also services VCOM
DISP_W = 400        # Pixels wide
DISP_H = 240        # Pixels tall

# --- Hardware ----------------------------------------------------------------

# Order must match the pins tuple in Hardware._init_buttons -- keypad.Keys
# reports events by index into that tuple, not by name.
BUTTON_NAMES = ("arm", "chirp", "menu")


class Hardware:
    def __init__(self):
        self.i2c = None
        self.gps = None
        self.radio = None
        self.display = None
        self.keys = None
        self.errors = []
        self.vbat = None

    def init_all(self):
        self._init_i2c()
        self._init_gps()
        self._init_radio()
        self._init_display()
        self._init_buttons()
        self._init_vbat()
        return len(self.errors) == 0

    def _init_i2c(self):
        try:
            self.i2c = board.STEMMA_I2C()
        except Exception:
            try:
                self.i2c = busio.I2C(board.SCL, board.SDA)
            except Exception as e:
                self.errors.append("i2c: {}".format(e))

    def _init_gps(self):
        if not self.i2c:
            return
        try:
            import adafruit_gps

            self.gps = adafruit_gps.GPS_GtopI2C(self.i2c, debug=False)
            self.gps.send_command(b"PMTK314,0,1,0,1,0,0,0,0,0,0,0,0,0,0,0,0,0,0,0")
            self.gps.send_command(b"PMTK220,1000")
            # SBAS/WAAS narrows single-unit error from ~5-10m to ~1-3m under open
            # sky (No effect indoors/under tree cover). Two independent receivers
            # still won't agree to zero -- their errors are uncorrelated.
            self.gps.send_command(b"PMTK313,1")
            self.gps.send_command(b"PMTK301,2")
        except Exception as e:
            self.errors.append("gps: {}".format(e))

    def _init_radio(self):
        try:
            import adafruit_rfm9x

            spi = board.SPI()
            cs = digitalio.DigitalInOut(board.RFM_CS)
            rst = digitalio.DigitalInOut(board.RFM_RST)
            self.radio = adafruit_rfm9x.RFM9x(spi, cs, rst, 915.0)
            self.radio.tx_power = 20
            self.radio.spreading_factor = 7
            self.radio.signal_bandwidth = 125000
            self.radio.coding_rate = 5
            self.radio.enable_crc = True
            try:
                self.radio.sync_word = packet.SYNC_WORD
            except Exception:
                pass
        except Exception as e:
            self.errors.append("radio: {}".format(e))

    def _init_display(self):
        try:
            import adafruit_sharpmemorydisplay

            spi = board.SPI()
            cs = digitalio.DigitalInOut(board.D6)  # verify against wiring
            self.display = adafruit_sharpmemorydisplay.SharpMemoryDisplay(
                spi, cs, DISP_W, DISP_H
            )
            self.display.fill(1)  # 1 = light on this panel
            self.display.show()
        except Exception as e:
            self.errors.append("display: {}".format(e))
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

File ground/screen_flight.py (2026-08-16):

"""FLIGHT screen: whimsy over density -- a rocket illustration plus two
compact "systems check" tables (the rocket's, then the handheld's own),
rather than a wall of raw numbers. Raw per-axis/link numbers still live on
DIAG for anyone who wants them.

The default screen -- ARM/DISARM only sends its command here (see
screen_footer.py and code.py's button dispatch), so the payload's battery
voltage stays as an exact number, not just a percentage: it gates the
NO-GO banner below.
"""

import handheld_art
import icons
import rocket_art
import units
from display_util import text
from nav import haversine_m
from packet import Sensor

ROCKET_X = 4
ROCKET_Y = 44
TABLE_X = ROCKET_X + rocket_art.ROCKET_ART_W + 6
RX = 265  # MISSION CONTROL column start -- clears "ACCELEROMETER: OFFLINE" (worst case) with room to spare
HANDHELD_Y = 44
MC_TABLE_Y = HANDHELD_Y + handheld_art.HANDHELD_ART_H + 4
STATUS_Y = 204  # alert / command-status band, above the footer


def _online(tel, bit):
    return "ONLINE" if tel["sensors"] & bit else "OFFLINE"


def draw(display, frame):
    tel = frame.tel
    link = frame.link

    rocket_art.draw(display, ROCKET_X, ROCKET_Y, armed=frame.armed, scale=1)

    # ----- ROCKET systems check ------------------------------------------
    text(display, TABLE_X, 44, "ROCKET", size=2)
    text(display, TABLE_X, 64, "SYSTEMS CHECK:")
    text(display, TABLE_X, 78,  "ATMOSPHERE:      {}".format(_online(tel, Sensor.BARO)))
    text(display, TABLE_X, 90,  "ACCELEROMETER:   {}".format(_online(tel, Sensor.IMU)))
    text(display, TABLE_X, 102, "MAGNETOMETER:    {}".format(_online(tel, Sensor.MAG)))
    text(display, TABLE_X, 114, "FILESYSTEM:      {}".format(_online(tel, Sensor.LOG)))
    text(display, TABLE_X, 126, "GPS LOCK:        {}".format("FIXED" if tel["has_fix"] else "SEARCH"))
    text(display, TABLE_X, 138, "TEMPERATURE:     {:.1f}{}".format(
        units.temperature(tel["temp_c"]), units.temperature_label()))
    text(display, TABLE_X, 150, "ALTITUDE:        {:.1f}{}".format(
        units.distance(tel["alt_baro_m"]), units.distance_label()))
    text(display, TABLE_X, 162, "BATTERY:         {}%{}".format(
        icons.battery_percent(tel["batt_volts"]),
        " CHG" if tel["sensors"] & Sensor.CHG else ""))
    text(display, TABLE_X, 174, "SIGNAL STRENGTH: {}%".format(icons.signal_percent(link.rssi)))
    text(display, TABLE_X, 186, "STATUS:          {}".format(tel["state_name"]))

    # ----- MISSION CONTROL (handheld) systems check ----------------------
    handheld_art.draw(display, RX, HANDHELD_Y, scale=1)

    text(display, RX, MC_TABLE_Y, "CONTROLLER", size=2)
    text(display, RX, MC_TABLE_Y + 21, "GPS LOCK: {}".format(
        "FIXED" if frame.my_lat is not None else "SEARCH"))
    text(display, RX, MC_TABLE_Y + 33, "BATTERY:  {}%{}".format(
        icons.battery_percent(frame.my_batt),
        " CHG" if frame.my_charging else ""))
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

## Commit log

2026-07-22 draft fritzing sketch
    [payload.fzz]
2026-07-23 fritzing sketches + Adafruit libs
    [handheld.fzz, payload.fzz]
2026-07-26 track the firmware
2026-07-26 reorg, add some docs
    [handheld.fzz, payload.fzz]
2026-08-14 fix payload boot regression
    [boot.py]
